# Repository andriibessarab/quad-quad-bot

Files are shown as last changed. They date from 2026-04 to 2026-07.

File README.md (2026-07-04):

<p>
  
</p>
<small>
  Custom desktop-size quadruped robot — from design and CAD to ROS 2 simulation and a physical build.
</small>

<hr/>

## About

**Quad-Quad Bot** is a quadruped (four-legged) robot built by me as a solo side-project. It spans the full mechatronics stack:

- **Mechanical** — from-scratch design, CAD in SolidWorks, and 3D-printed parts.
- **Electronics** — custom power distribution, motor drivers, onboard compute
- **Software** — ROS 2 (Jazzy), Gazebo Harmonic simulation, inverse kinematics, gait planning, and feedback loops.

<i> Current status: simulation is running with a trot gait. Hardware assembled. Currently tuning walking gaits(crawl, trot, and maybe gallop). </i>

<hr/>

## Gallery

<table>
  <tr>
    <td align="center" width="50%">
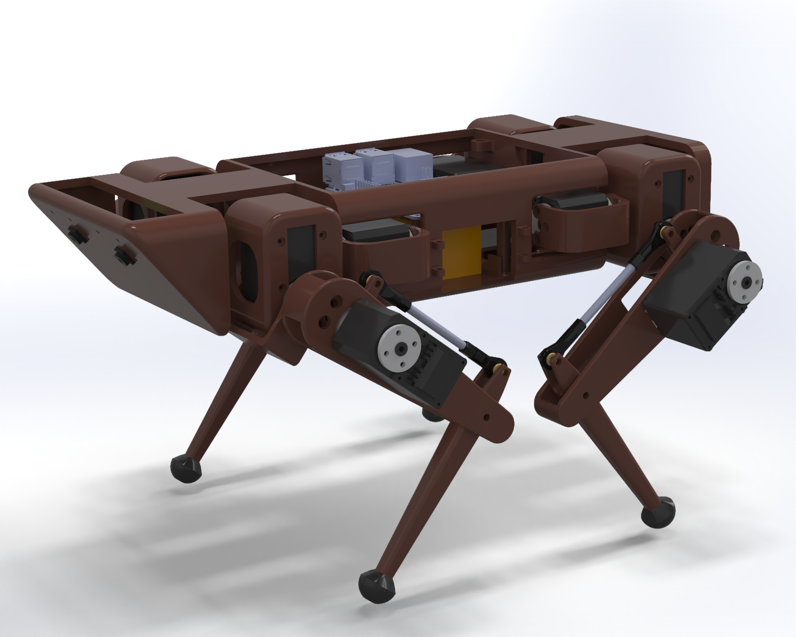
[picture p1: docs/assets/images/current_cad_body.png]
CAD render
      
      <br/><br/><b>CAD Model</b>
    </td>
    <td align="center" width="50%">
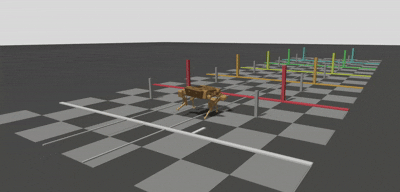
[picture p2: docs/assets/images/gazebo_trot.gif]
Gazebo simulation
      
      <br/><br/><b>Gazebo Trot</b>
    </td>
  </tr>
  <tr>
    <td align="center" width="50%">
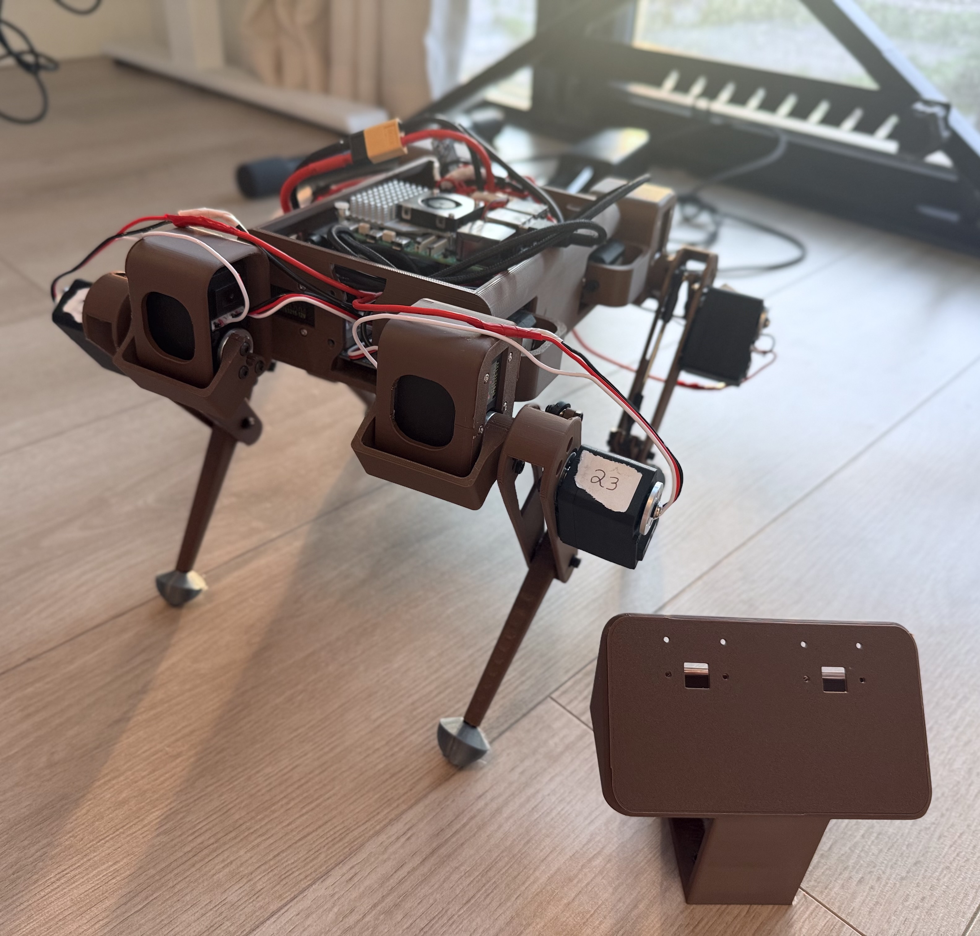
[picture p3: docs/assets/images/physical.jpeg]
Physical robot
      
      <br/><br/><b>Hardware <i>(WIP)</i></b>
    </td>
    <td align="center" width="50%">
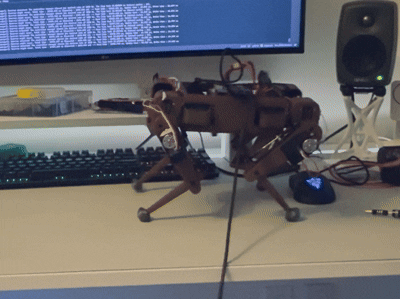
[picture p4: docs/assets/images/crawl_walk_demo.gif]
Walk Demo
      
      <br/><br/><b>Walk Demo</b>
    </td>
  </tr>
</table>

<hr/>

## Repository Structure

```
quad-quad-bot/
├── ros2_ws/         # ROS 2 workspace — all software (nodes, controllers, bringup)
├── design/
│   ├── cad/         # SolidWorks source files
│   ├── slicer/      # 3D print slicer projects
│   └── electrical/  # Wiring diagrams
└── docs/            # Technical documentation (MkDocs)
```

<hr/>

## Documentation
Full technical documentation can be found [here](https://quad-quad-bot.andriibessarab.com/). It is currently in TODO state.

<hr/>

<p><sub>Built by <a href="https://github.com/andriibessarab">Andrii Bessarab</a></sub></p>

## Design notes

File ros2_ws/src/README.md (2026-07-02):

# Packages

| Package | Description |
|---|---|
| `bot_bringup` | Top-level launch entry point for both sim and real hardware. |
| `bot_control` | Gait planner and locomotion commander nodes - computes foot targets and runs IK to produce joint commands. |
| `bot_description` | URDF/xacro robot model, joint limits, motor wiring config, and ros2_control hardware description. |
| `bot_hardware` | ros2_control `SystemInterface` plugin that drives all 12 STS servos over TTL-level, half-duplex, single-wire asynchronous serial  serial. |
| `bot_math` | Pure C++ library — IK solver and foot trajectory math. |
| `bot_sim` | Gazebo Harmonic world and robot spawn setup. |
| `bot_teleop` | Xbox controller → `/cmd_vel` via `joy_linux` and `teleop_twist_joy`. |

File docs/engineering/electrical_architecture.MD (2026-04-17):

# Electrical Architecture



---

## SS
The system has to primary tasks: to fly and to walk. Due to how different these two system operate - it was decided to take a "split-brain" approach.

Flying subsystem consistent 

Walking subsystem 

## Power Distribution

The system is powered by a single **850mAh 4S 95C LiPo battery**. Power is routed through an XT60 pigtail and split via a three-way junction to the SpeedyBee ESC, Matek Micro UBEC, and Hobbywing 25A UBEC. This parallel distribution isolates subsystems with fundamentally different voltage and current requirements.

### Logic Power
The **Matek Micro UBEC** steps down the primary battery voltage to a regulated 5V, supplying 1.5A continuous (2.5A peak). This provides the dedicated, low-current logic power required by the Raspberry Pi Zero processor.

### Leg Power
The **Hobbywing 25A UBEC** steps down battery voltage to 6.0V/7.4V to power the 12 Hiwonder servos. These servos possess a collective theoretical stall current of 30A (12 servos × 2.5A). A standard, lower-rated UBEC would fail under the load of demanding maneuvers.

Because standard 2.54mm pin headers are generally only rated for ~3A of continuous current, drawing 25A–50A through a single port would result in thermal failure. To safely manage this, the UBEC's 8 output ports are wired in parallel to form a custom high-current distribution bus. This architecture shares the load, reducing the maximum current draw per individual pin to safe operating margins (3.75A per pin under a 30A peak load) before distributing it out to the 12 servos.

The ground rail follows the same parallel bus architecture. In addition to the 12 servo ground returns, a dedicated synchronization wire connects this high-current ground bus directly to a GND pin on the PCA9685 to ensure a common zero-volt reference across the logic and actuation systems.

### Flight Power
The **SpeedyBee ESC** receives raw battery voltage to directly drive the four FlyFishRC Flash 1804 3500KV motors. The ESC also passes this raw battery voltage up to the SpeedyBee Flight Controller mounted on top of it, which regulates its own internal logic power via an integrated voltage regulator.

### Auxiliary Power Routing
* **PCA9685 (PWM Driver):** Receives 3.3V logic power from the Raspberry Pi. To prevent  thermal failure of the board's internal copper traces, the PCA9685's terminal block is deliberately bypassed. The 30A servo actuation current is routed entirely through the external parallel bus.
* **Radio Link:** The Radiomaster RP2 V2 TCXO receiver draws its 5V logic power directly from a dedicated 5V pad on the SpeedyBee FC.
* **Pi Cam:** Raspberry Pi Camera V2 is connected to Raspberry Pi through CSI cable which is used for both data and power transfer.

---

## Communications & Logic Architecture

Data routing across the system is strictly delineated by subsystem to ensure the Linux-based environment of the Raspberry Pi does not interrupt the real-time processing of the flight controller. The communication topologies are divided into the following discrete channels:

### Vision System (Raspberry Pi & Pi Camera)
* **Interface:** MIPI CSI-2
* **Implementation:** Connected via a dedicated flat ribbon cable.
* **Function:** Provides a high-bandwidth, direct memory access (DMA) pipeline for raw video data transfer from the camera module to the Pi Zero 2 W, enabling low-latency computer vision and automation processing.

### Kinematics Control Loop (Raspberry Pi & PCA9685)
* **Interface:** I2C Bus
* **Implementation:** Pi SDA connects to PCA9685 SDA; Pi SCL connects to PCA9685 SCL.
* **Function:** The Pi does complex calculations in ROS and transmits the resulting multi-channel positioning commands over the I2C bus to the PCA9685. The PCA9685 then generates the precise hardware-level PWM signals required to actuate the 12 Hiwonder servos.

### Companion Computer Link (Raspberry Pi & SpeedyBee FC)
* **Interface:** Bi-directional Asynchronous Serial (UART)
* **Implementation:** Crossed logic lines; Pi TX connects to FC RX, and Pi RX connects to FC TX.
* **Function:** The Raspberry Pi acts as a "Companion Computer" to the Flight Controller. This bi-directional link serves a dual purpose:
    1. **Telemetry Stream:** The Pi receives high-frequency IMU data from the FC.
    2. **Offboard Control:** Pi transmits high-level autonomous flight directives derived from its vision processing. The FC receives these commands and handles the critical, low-level PID motor mixing required to execute them safely.

### **Manual Pilot Override (SpeedyBee** FC & Radio Link)
* **Interface:** Serial (UART)
* **Implementation:** Radiomaster RP2 V2 TCXO receiver wired to the FC's TX and RX pads.
* **Function:** Provides a direct, hardware-level pilot override and fail-safe mechanism. Because it communicates directly with the Flight Controller, manual flight control and emergency motor-kill switches remain fully operational even in the event of a Raspberry Pi OS crash or automation loop failure.

---

## Pinout Tables
This will be added at later point.

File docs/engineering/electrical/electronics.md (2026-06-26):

# Electronics

## Compute Board

## Flight Stack

## Camera

## Radio Receiver

## Integration Notes

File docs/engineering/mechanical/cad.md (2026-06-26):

# CAD

## Design Overview

## SolidWorks Workflow

## Key Design Decisions

## Link Geometry & Dimensions

## Revision History

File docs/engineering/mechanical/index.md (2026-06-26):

# Mechanical

- [CAD](cad.md)
- [Manufacturing](manufacturing.md)

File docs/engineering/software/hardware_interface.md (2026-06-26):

# Hardware Interface

## STS3215 Servo Protocol

## ros2_control Plugin

## Servo ID Mapping

## Calibration Procedure

### Setting zero_count

### Setting direction

## Serial Port Setup

## Pre-Power Safety Checklist

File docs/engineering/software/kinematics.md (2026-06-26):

# Kinematics

## Limb Geometry

## HAA Derivation

## HFE / KFE Derivation

## Singularity Cases

## Link Dimensions

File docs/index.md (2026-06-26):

# Introduction

Current Cad

Hey there! I'm **Andrii** - a 1st-year **Tron student at Waterloo**. For a while, I have wanted to tackle a serious solo
robotics project, and this is the result.

In short, the goal is to build a **quadruped robot** (think Boston Dynamics) that can also transition into **flight mode
** (aka quadcopter). It is a unique challenge that will force me to get hands-on with a massive set of tools, including
**CAD, kinematics, ROS, simulations, 3D printing, electronics, vision processing**, and more.

What you are looking at is the technical documentation for this project, covering the full stack from CAD and electronics to kinematics and software.

I don’t have a set timeline or a final vision yet, so the scope is bound to change as I work through this project...

---

<div class="grid" markdown>

[Engineering Details](engineering/){: .md-button }

</div>

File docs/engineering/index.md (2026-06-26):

# Engineering

- [Mechanical](mechanical/index.md) — CAD, manufacturing, assembly
- [Electrical](electrical/index.md) — power distribution, wiring, electronics
- [Software](software/index.md) — ROS architecture, kinematics, gait, simulation
- [BOM](bom.md) — bill of materials

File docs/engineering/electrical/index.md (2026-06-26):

# Electrical

- [Power](power.md)
- [Wiring](wiring.md)
- [Electronics](electronics.md)

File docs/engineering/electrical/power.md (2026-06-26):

# Power

## Power Budget

## Battery

## Power Distribution

### Servo UBEC

### Compute UBEC

## Wiring Diagram

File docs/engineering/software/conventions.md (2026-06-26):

# Conventions

## Zero Position

## Joint Sign Conventions

### HAA (Hip Abduction/Adduction)

### HFE (Hip Flexion/Extension)

### KFE (Knee Flexion/Extension)

## IK Target Frame

## IK Output Conventions

## Commander Inversion Table

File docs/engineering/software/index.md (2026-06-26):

# Software

- [Conventions](conventions.md)
- [Kinematics](kinematics.md)
- [Gait](gait.md)
- [Architecture](architecture.md)
- [URDF / Xacro](urdf.md)
- [Simulation](simulation.md)
- [Hardware Interface](hardware_interface.md)

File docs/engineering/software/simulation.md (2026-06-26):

# Simulation

## Prerequisites

## Quick Start

## Manual Joint Testing

## Changing Meshes & Rebuilding URDF

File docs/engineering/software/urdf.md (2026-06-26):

# URDF / Xacro Structure

## File Hierarchy

## Joint Naming Convention

## Limb Macro Parameters

## Joint Limits

## Regenerating from SolidWorks Export

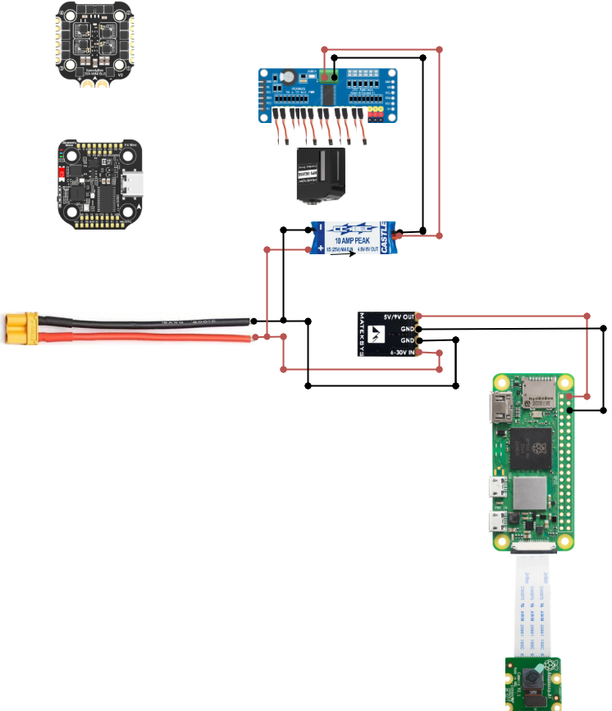
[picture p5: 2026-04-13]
electronics/schematics/main_electronics_scheme.drawio.png

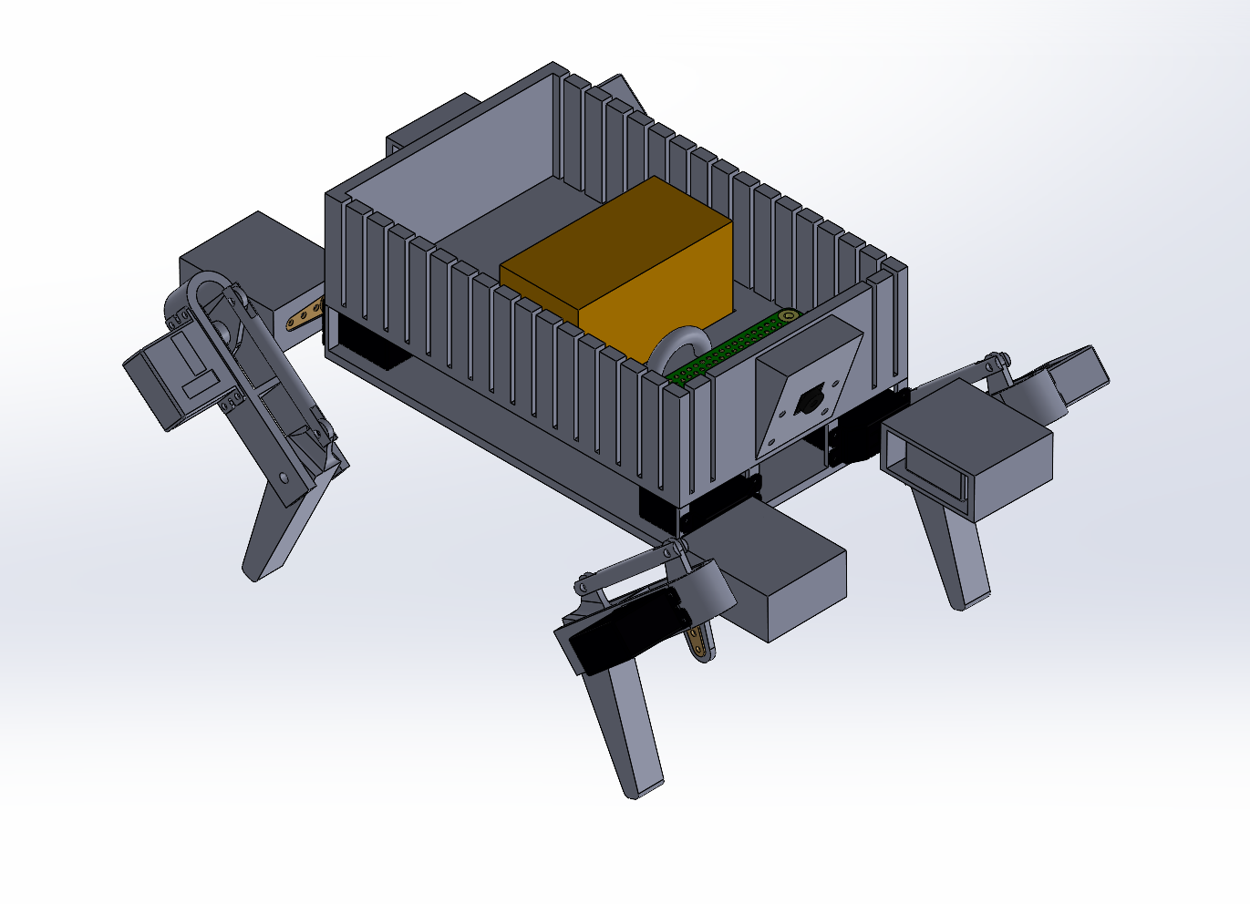
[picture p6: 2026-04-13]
docs/assets/images/cad_first_version.png

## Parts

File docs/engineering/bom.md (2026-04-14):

# Bill of Materials

## Compute & Vision

| Functional Name | Part Name | Qty | Mass (g) | Est. Cost (CAD) | Link |
|:---|:---|:----|:---|:---|:---|
| **High-Level Processor** | Raspberry Pi Zero 2 W  | 1 | 9.0 | 32.99 | [Amazon](https://www.amazon.ca/Raspberry-Zero-Wireless-Bluetooth-2021/dp/B09LH5SBPS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) |
| **Vision Sensor** | Raspberry Pi Camera V2 | 1 | 3.0 | 32.99 | [Amazon](https://www.amazon.ca/Raspberry-Pi-Camera-Module-Megapixel/dp/B01ER2SKFS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) |
| **SD Card** | SD Card | | | | |

## Flight Systems

| Component | Part Name | Qty | Mass (g) | Est. Cost (CAD) | Link |
|:---|:---|:----|:---|:---|:---|
| **Flight Stack** | SpeedyBee F405 Mini BLS 35A 20x20mm Stack | 1 | 13.5 | 89.99 | [Great Hobbies](https://www.greathobbies.com/productinfo/?prod_id=SPBF4MINI-ST) |
| **BLDC Flight Motors** | FlyFishRC Flash 1804 3500KV | 4 | 14.0 | 22.99 | [Rotor Village](https://rotorvillage.ca/flyfishrc-flash-1804-3500kv-freestyle-motor/) |
| **Propellers** | Gemfan Hurricane T3525 Props (2CW+2CCW) | 1 | 3.78 | 4.69 | [Rotor Village](https://rotorvillage.ca/gemfan-51433-hurricane-tri-blade-prop-2cw-2ccw/) |
| **Radio Link** | Radiomaster RP2 V2 TCXO ExpressLRS 2.4GHz Receiver | 1 | 0.55 | 27.99 | [Rotor Village](https://rotorvillage.ca/radiomaster-rp2-v2-tcxo-expresslrs-2-4ghz-receiver/) |

## Actuation & Limb Control

| Component | Part Name | Qty | Mass (g) | Est. Cost (CAD) | Link |
|:---|:---|:----|:---|:---|:---|
| **PWM PWM Servo Driver** | JZK PCA9685 16 Channel 12-Bit PWM Servo Motor Driver | 1 | 11.0 | 10.59 | [Amazon](https://www.amazon.ca/JZK-PCA9685-Channel-12-Bit-Arduino/dp/B06XSFFXQY) |
| **Limb Servos** | Hiwonder HPS-0618SG | 12  | 14.5 | 33.16 | [Amazon](https://www.amazon.com/Hiwonder-Coreless-0-06sec-Stainless-Robotic/dp/B09TVNFN5N) |
| **Joint Bearings** | F683ZZ Flanged Bearings | 12  | 1.8 | 16.59 / 10 | [Amazon](https://www.amazon.ca/uxcell-Flanged-Bearing-Shielded-Bearings/dp/B07Z3DRZX9) |

## Power Distribution

| Component | Part Name | Qty | Mass (g) | Est. Cost (CAD) | Link |
|:---|:---|:----|:---|:---|:---|
| **Battery** | Tattu R-Line 850mAh 4S 95C Lipo XT60 | 1 | 104 ± 20 | 30.99 | [Roter Village](https://rotorvillage.ca/tattu-r-line-850mah-4s-95c-lipo-xt60) |
| **High-Current Servo UBEC** | Hobbywing UBEC 25A HV | 1 | 74.0 | 106.99 | [RotorQuest](https://rotorquest.com/products/ubec-25a-hv) |
| **Processor UBEC** | Matek Micro BEC (5V/9V) | 1 | 1.0 | 13.99 / 3 | [Roter Village](https://rotorvillage.ca/Matek-Micro-BEC-6-30V-5V/9V-Adjustable/) |
| **Battery Pigtail** | Padarsey 2 Pair XT60 Connector 10CM Silicon Wire 14AWG | 1 | | 9.99 / 4 | [Amazon](https://www.amazon.ca/Padarsey-Connector-Female-Housing-Silicon/dp/B07BF8154S) |

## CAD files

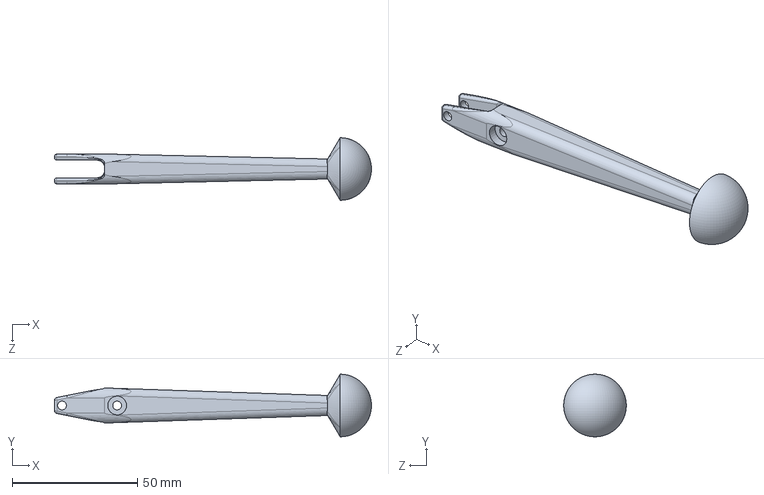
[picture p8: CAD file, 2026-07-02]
design/cad/parts/tibia.SLDPRT
126.5 x 25.0 x 25.0 mm

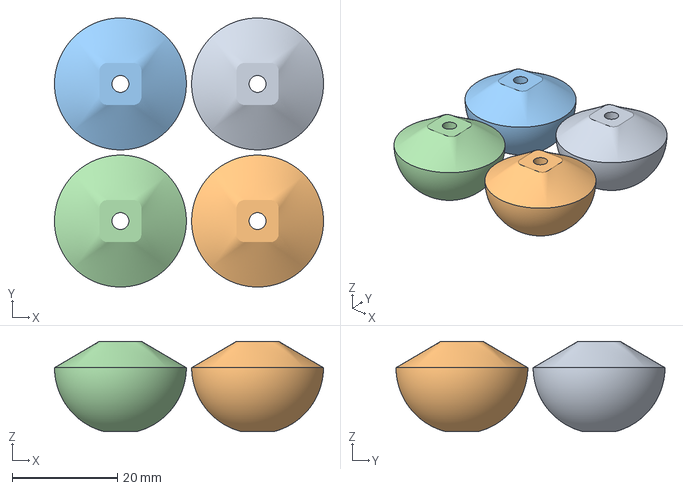
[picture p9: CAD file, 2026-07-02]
design/slicer/tibia_spherical_foot.3mf
51.0 x 51.0 x 17.1 mm
tibia_spherical_foot.STEP x 4

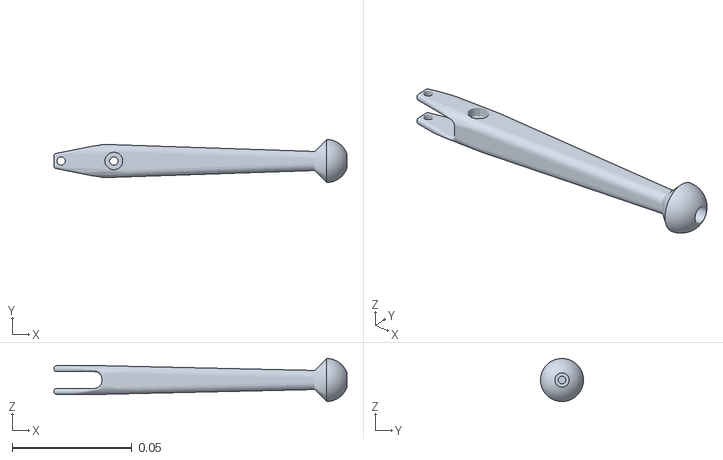
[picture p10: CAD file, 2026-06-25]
ros2_ws/src/bot_description/meshes/tibia_link.STL
0.122 x 0.018 x 0.018

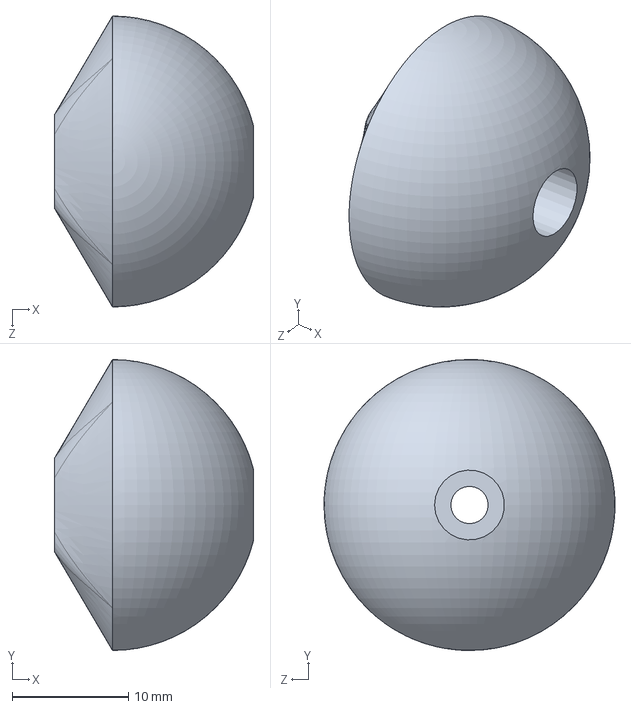
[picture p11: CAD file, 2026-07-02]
design/cad/parts/tibia_spherical_foot.SLDPRT
17.1 x 25.0 x 25.0 mm

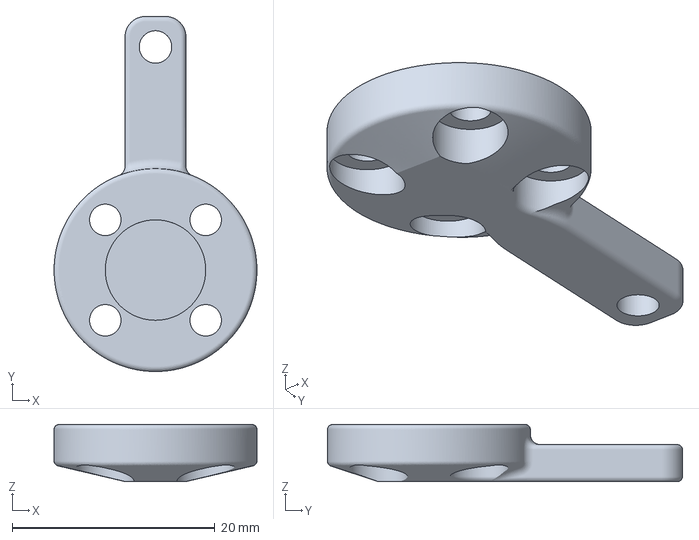
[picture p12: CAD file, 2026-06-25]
design/slicer/link_tab.3mf
20.0 x 35.0 x 5.64 mm

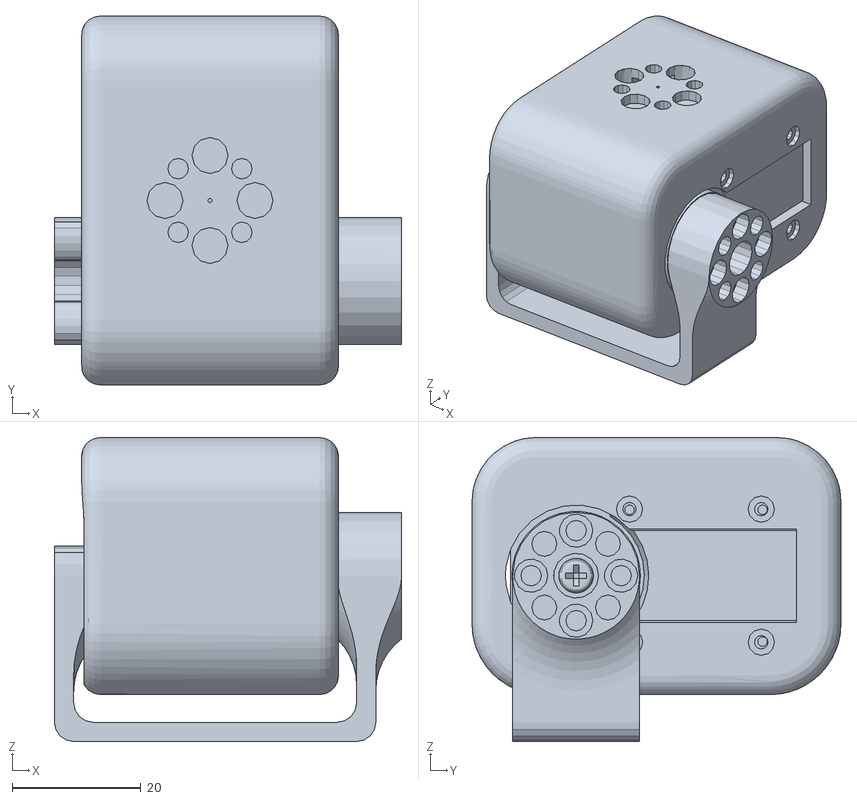
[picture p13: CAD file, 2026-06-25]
ros2_ws/src/bot_description/meshes/inverted_shoulder_link.STL
54.0 x 57.4 x 47.3

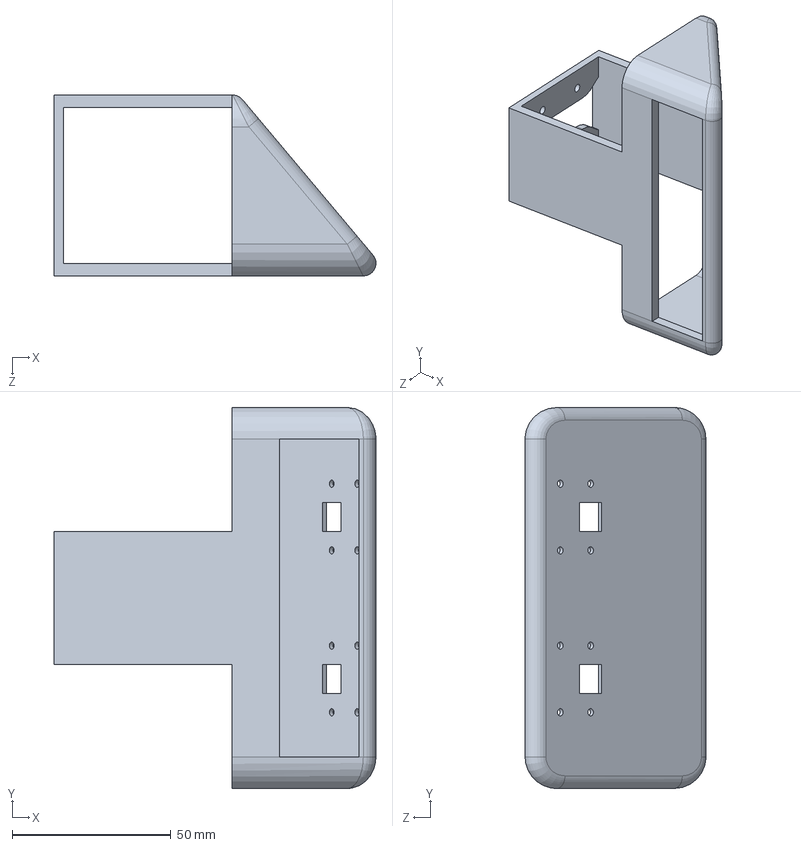
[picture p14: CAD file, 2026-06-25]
design/cad/parts/casing_front.SLDPRT
101.4 x 120.0 x 57.0 mm

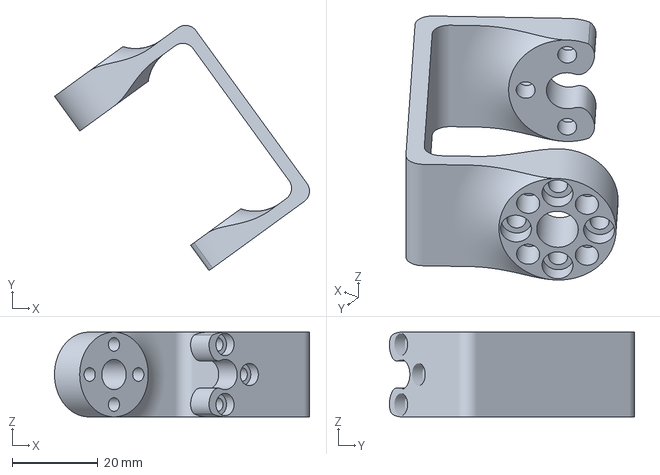
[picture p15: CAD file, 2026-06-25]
design/slicer/sts3215_coaxial_stradded_bracket_hfe.3mf
59.4 x 57.1 x 19.7 mm

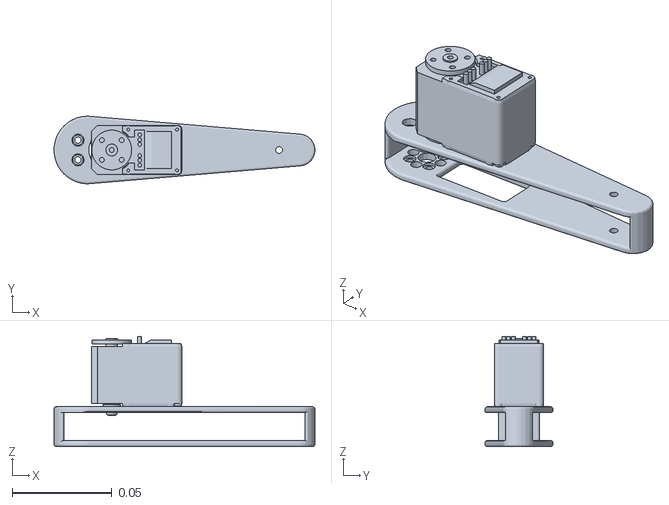
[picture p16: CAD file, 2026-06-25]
ros2_ws/src/bot_description/meshes/femur_link.STL
0.131 x 0.034 x 0.0553

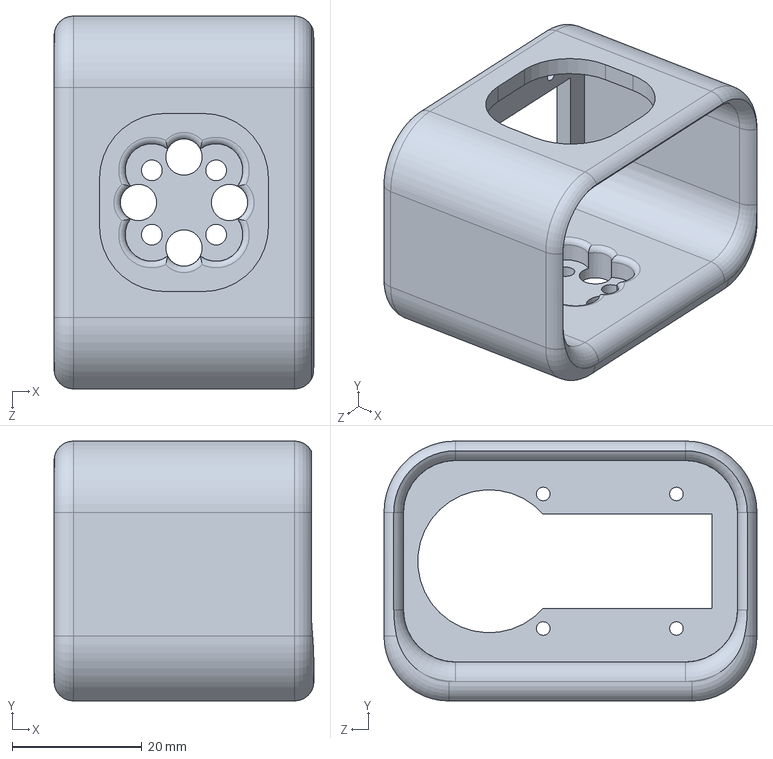
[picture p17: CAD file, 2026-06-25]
design/cad/parts/mirrored_shoulder.SLDPRT
40.0 x 40.0 x 57.4 mm

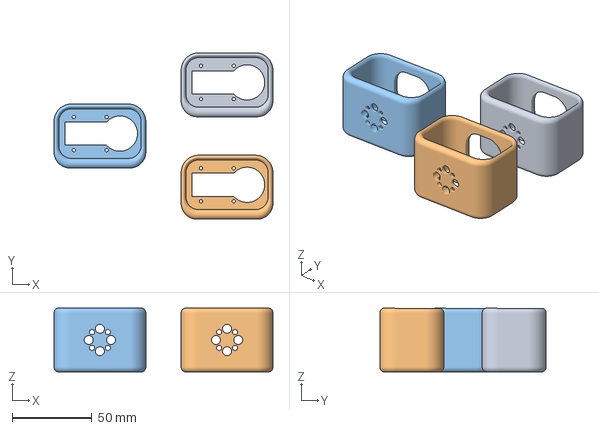
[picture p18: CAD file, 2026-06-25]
design/slicer/shoulder.3mf
136.9 x 104.0 x 40.0 mm
shoulder.STEP x 3

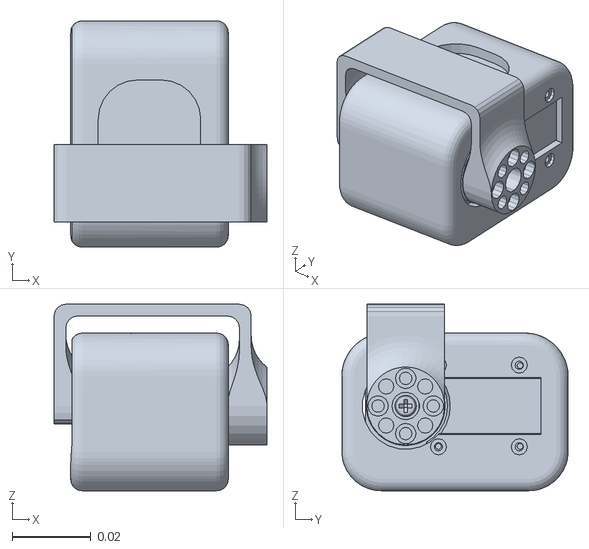
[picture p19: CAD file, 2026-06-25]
ros2_ws/src/bot_description/meshes/shoulder_link.STL
0.054 x 0.0574 x 0.0473

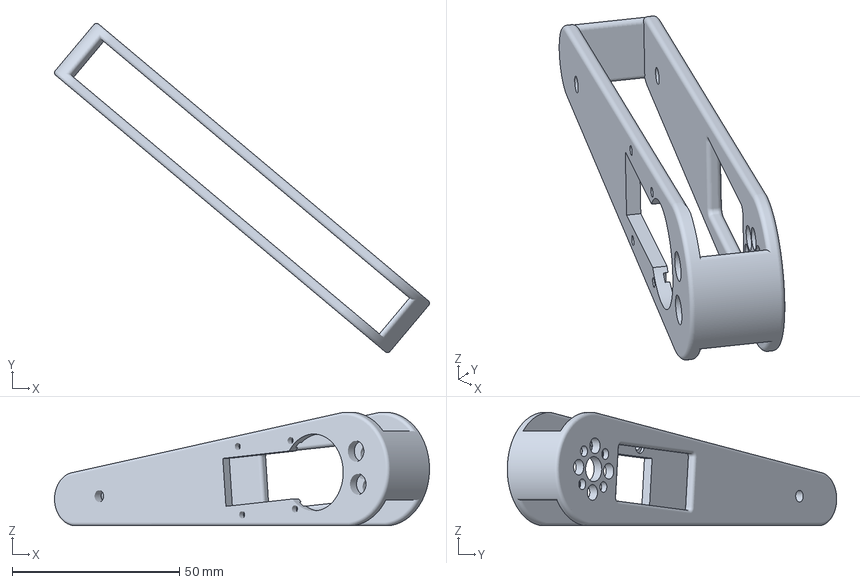
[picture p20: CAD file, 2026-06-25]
design/slicer/femur.3mf
112.2 x 98.5 x 33.9 mm

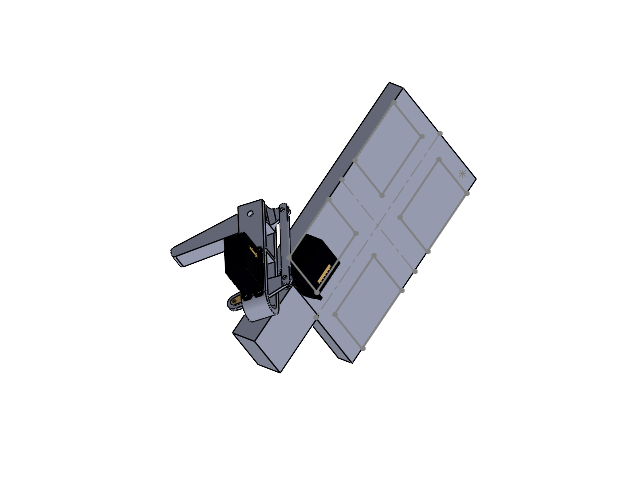
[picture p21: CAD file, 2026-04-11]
cad/Body.SLDASM
parttruc x 3
Tibia
Femur
Knee Link Rod
Knee Link Tab
servoPWM x 3
Shoulder
Part1^Body

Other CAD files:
design/cad/assemblies/limb_sub.SLDASM
design/cad/assemblies/chassis_sub.SLDASM
design/cad/assemblies/bot_master_assembly.SLDASM
design/cad/parts/shoulder.SLDPRT
design/cad/cots/actuators/HiWonder_HPS-0618SG/banhlai.SLDPRT
design/cad/cots/actuators/HiWonder_HPS-0618SG/parttruc.SLDPRT
design/cad/cots/actuators/HiWonder_HPS-0618SG/servoPWM.SLDPRT
design/cad/cots/actuators/STS3215_03a v1.step
design/cad/cots/electronics/KCD4_ROCKET_SWITCH.SLDPRT
design/cad/cots/electronics/PCA9685.step
design/cad/cots/electronics/RaspberryPi5.step
design/cad/cots/electronics/raspberry-pi-camera-v2.SLDPRT
design/cad/cots/electronics/‎WSH-SBS-01.SLDPRT
design/cad/cots/fasteners/Metric_Socket_Cap_Head_Screws/M3/Screw_DIN_912_M3x10F_A2.SLDPRT
design/cad/cots/fasteners/Metric_Socket_Cap_Head_Screws/M3/Screw_DIN_912_M3x12F_A2.SLDPRT
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

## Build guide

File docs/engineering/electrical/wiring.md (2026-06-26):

# Wiring

## Servo Bus

## Connector Types

## Harness Layout

## Pinouts

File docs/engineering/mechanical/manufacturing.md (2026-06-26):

# Manufacturing

## 3D Printing

### Print Settings

### Material

### Tolerances & Fit

## Assembly Order

## Known Issues & Mitigations

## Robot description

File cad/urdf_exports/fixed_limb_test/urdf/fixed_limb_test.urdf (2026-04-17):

<?xml version="1.0" encoding="utf-8"?>
<!-- This URDF was automatically created by SolidWorks to URDF Exporter! Originally created by Stephen Brawner (brawner@gmail.com) 
     Commit Version: 1.6.0-4-g7f85cfe  Build Version: 1.6.7995.38578
     For more information, please see http://wiki.ros.org/sw_urdf_exporter -->
<robot name="fixed_limb_test">
  <link name="base_link">
    <inertial>
      <origin xyz="0.012807313311312 0.00598090852226242 -0.0117251285139543" rpy="0 0 0" />
      <mass value="0.00723402556361831" />
      <inertia ixx="4.05147247523767E-07" ixy="3.01231584549377E-10" ixz="-1.88167986432032E-08" iyy="7.38938259329422E-07" iyz="7.90595902470049E-10" izz="5.0342421323583E-07" />
    </inertial>
    <visual>
      <origin xyz="0 0 0" rpy="0 0 0" />
      <geometry>
        <mesh filename="package://fixed_limb_test/meshes/base_link.STL" />
      </geometry>
      <material name="">
        <color rgba="0.00392156862745098 0 0.0196078431372549 1" />
      </material>
    </visual>
    <collision>
      <origin xyz="0 0 0" rpy="0 0 0" />
      <geometry>
        <mesh filename="package://fixed_limb_test/meshes/base_link.STL" />
      </geometry>
    </collision>
  </link>
  <link name="shoulder_link">
    <inertial>
      <origin xyz="0.00770399429191724 9.32504877206378E-06 0.0207339193469641" rpy="0 0 0" />
      <mass value="0.0148104574438063" />
      <inertia ixx="1.88189230614178E-06" ixy="3.01231584549858E-10" ixz="1.68325026936694E-08" iyy="2.59134654836223E-06" iyz="-7.90595902469875E-10" izz="1.39963201919848E-06" />
    </inertial>
    <visual>
      <origin xyz="0 0 0" rpy="0 0 0" />
      <geometry>
        <mesh filename="package://fixed_limb_test/meshes/shoulder_link.STL" />
      </geometry>
      <material name="">
        <color rgba="0.545098039215686 0.615686274509804 0.858823529411765 1" />
      </material>
    </visual>
    <collision>
      <origin xyz="0 0 0" rpy="0 0 0" />
      <geometry>
        <mesh filename="package://fixed_limb_test/meshes/shoulder_link.STL" />
      </geometry>
    </collision>
  </link>
  <joint name="haa_joint" type="revolute">
    <origin xyz="-0.001 0.006 -0.016" rpy="3.1416 -1.5708 0" />
    <parent link="base_link" />
    <child link="shoulder_link" />
    <axis xyz="0 0 1" />
    <limit lower="-1.5708" upper="0" effort="0" velocity="0" />
  </joint>
  <link name="femur_link">
    <inertial>
      <origin xyz="0.0124792168310497 9.99428181540189E-06 0.0185705130302731" rpy="0 0 0" />
      <mass value="0.0138239022547814" />
      <inertia ixx="8.42245738682422E-07" ixy="-7.91960713042997E-10" ixz="-9.47919040177247E-08" iyy="3.58798405876978E-06" iyz="-3.01970991415103E-10" izz="3.1267090240501E-06" />
    </inertial>
    <visual>
      <origin xyz="0 0 0" rpy="0 0 0" />
      <geometry>
        <mesh filename="package://fixed_limb_test/meshes/femur_link.STL" />
      </geometry>
      <material name="">
        <color rgba="0.866666666666667 0.909803921568627 1 1" />
      </material>
    </visual>
    <collision>
      <origin xyz="0 0 0" rpy="0 0 0" />
      <geometry>
        <mesh filename="package://fixed_limb_test/meshes/femur_link.STL" />
      </geometry>
    </collision>
  </link>
  <joint name="hfe_joint" type="revolute">
    <origin xyz="0.020875 0 0.0165" rpy="0 1.5708 0" />
    <parent link="shoulder_link" />
    <child link="femur_link" />
    <axis xyz="0 0 -1" />
    <limit lower="0" upper="3.14" effort="0" velocity="0" />
  </joint>
  <link name="tibia_link">
    <inertial>
      <origin xyz="0.0156981068181742 3.55361015266786E-09 7.93462496675047E-05" rpy="0 0 0" />
      <mass value="0.0070755567397191" />
      <inertia ixx="1.28214686803871E-07" ixy="4.5956055502833E-13" ixz="1.45828471109314E-08" iyy="1.81740201742321E-06" iyz="-7.36270952752015E-14" izz="1.83619400245263E-06" />
    </inertial>
    <visual>
      <origin xyz="0 0 0" rpy="0 0 0" />
      <geometry>
        <mesh filename="package://fixed_limb_test/meshes/tibia_link.STL" />
      </geometry>
      <material name="">
        <color rgba="0.545098039215686 0.615686274509804 0.858823529411765 1" />
      </material>
    </visual>
    <collision>
      <origin xyz="0 0 0" rpy="0 0 0" />
      <geometry>
        <mesh filename="package://fixed_limb_test/meshes/tibia_link.STL" />
      </geometry>
    </collision>
  </link>
  <joint name="knee_joint" type="revolute">
    <origin xyz="0.046 0 0.0106" rpy="-3.1416 0 1.5708" />
    <parent link="femur_link" />
    <child link="tibia_link" />
    <axis xyz="0 0 1" />
    <limit lower="-0.87267" upper="0.87267" effort="0" velocity="0" />
  </joint>
  <link name="tab_link">
    <inertial>
      <origin xyz="-0.00203367196621368 -6.01949046163952E-16 0.00395500792852426" rpy="0 0 0" />
      <mass value="0.00116134718742782" />
      <inertia ixx="9.1005400789047E-09" ixy="-7.94186594852218E-22" ixz="1.61623668129035E-09" iyy="8.60231140276365E-08" iyz="-2.37565391241938E-23" izz="9.3647667205365E-08" />
    </inertial>
    <visual>
      <origin xyz="0 0 0" rpy="0 0 0" />
      <geometry>
        <mesh filename="package://fixed_limb_test/meshes/tab_link.STL" />
      </geometry>
      <material name="">
        <color rgba="0.866666666666667 0.909803921568627 1 1" />
      </material>
    </visual>
    <collision>
      <origin xyz="0 0 0" rpy="0 0 0" />
      <geometry>
        <mesh filename="package://fixed_limb_test/meshes/tab_link.STL" />
      </geometry>
    </collision>
  </link>
  <joint name="kfe_motor_joint" type="revolute">
    <origin xyz="0.002 0 0.0132" rpy="-3.1416 0 -1.5708" />
    <parent link="femur_link" />
    <child link="tab_link" />
    <axis xyz="0 0 -1" />
    <limit lower="-0.87267" upper="0.87267" effort="0" velocity="0" />
  </joint>
  <link name="rod_link">
    <inertial>
      <origin xyz="0.021999975174988 7.77439050636541E-09 -6.17363184046704E-08" rpy="0 0 0" />
      <mass value="0.000929490166689096" />
      <inertia ixx="3.11724892800746E-09" ixy="-1.76984253516657E-14" ixz="1.0644090388813E-13" iyy="1.38486128282688E-07" iyz="5.69419412480685E-14" izz="1.38113398710736E-07" />
    </inertial>
    <visual>
      <origin xyz="0 0 0" rpy="0 0 0" />
      <geometry>
        <mesh filename="package://fixed_limb_test/meshes/rod_link.STL" />
      </geometry>
      <material name="">
        <color rgba="0.545098039215686 0.615686274509804 0.858823529411765 1" />
      </material>
    </visual>
    <collision>
      <origin xyz="0 0 0" rpy="0 0 0" />
      <geometry>
        <mesh filename="package://fixed_limb_test/meshes/rod_link.STL" />
      </geometry>
    </collision>
  </link>
  <joint name="rod_joint" type="revolute">
    <origin xyz="0.015 0 0.0045" rpy="0 0 -1.5708" />
    <parent link="tab_link" />
    <child link="rod_link" />
    <axis xyz="0 0 -1" />
    <limit lower="-0.87267" upper="0.87267" effort="0" velocity="0" />
  </joint>
</robot>

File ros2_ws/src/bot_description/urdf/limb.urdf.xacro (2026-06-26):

<?xml version="1.0" encoding="utf-8"?>

<robot xmlns:xacro="http://www.ros.org/wiki/xacro" name="limb">
    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
    <xacro:property name="limits" value="${xacro.load_yaml('$(find bot_description)/config/joint_limits.yaml')}"/>

    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
    <xacro:macro name="_limb_core" params="prefix inverted_shoulder hfe_axis_mult kfe_axis_mult">
        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
        <link name="${prefix}shoulder_link">
            <inertial>
                <origin xyz="0.00189283967211911 -0.00149022104022392 0.0209651260942884" rpy="0 0 0" />
                <mass value="0.0772984767866564" />
                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
            </inertial>
            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
        </link>
        <link name="${prefix}femur_link">
            <inertial>
                <origin xyz="0.0323249229136636 -9.62316571824495E-07 0.0265797029719004" rpy="0 0 0" />
                <mass value="0.0561441430721167" />
                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
            </inertial>
            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
        </link>
        <link name="${prefix}tibia_link">
            <inertial>
                <origin xyz="0.039043936151174 -1.78287788882986E-07 -1.41708728744472E-07" rpy="0 0 0" />
                <mass value="0.0146532231932923" />
                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
            </inertial>
            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
        </link>

        <joint name="${prefix}hfe_joint" type="revolute">
            <xacro:if value="${inverted_shoulder}">
                <origin xyz="0.0298000000000001 -0.0124999999999999 -0.0214999999999999" rpy="-1.5707963267949 0 -1.5707963267949"/>
            </xacro:if>
            <xacro:unless value="${inverted_shoulder}">
                <origin xyz="0.0298000000000001 -0.0124999999999999 0.0214999999999999" rpy="-1.5707963267949 0 -1.5707963267949"/>
            </xacro:unless>

            <parent link="${prefix}shoulder_link"/>
            <child link="${prefix}femur_link"/>
            <axis xyz="0 0 ${hfe_axis_mult * -1}"/>
            <limit lower="${limits['hfe']['lower']}" upper="${limits['hfe']['upper']}" effort="${limits['hfe']['effort']}" velocity="${limits['hfe']['velocity']}"/>
        </joint>

        <joint name="${prefix}kfe_joint" type="revolute">
            <origin xyz="0.0960572429044665 0 0.00999999999999993" rpy="-3.14159265358979 0 0"/>
            <parent link="${prefix}femur_link"/>
            <child link="${prefix}tibia_link"/>
            <axis xyz="0 0 ${kfe_axis_mult * 1}"/>
            <limit lower="${limits['kfe']['lower']}" upper="${limits['kfe']['upper']}" effort="${limits['kfe']['effort']}" velocity="${limits['kfe']['velocity']}"/>
        </joint>
    </xacro:macro>

    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
    <xacro:macro name="limb" params="prefix x y z r p yw parent_link:=body_link inverted_shoulder hfe_axis_mult kfe_axis_mult">
        <xacro:_limb_core prefix="${prefix}_" inverted_shoulder="${inverted_shoulder}" hfe_axis_mult="${hfe_axis_mult}" kfe_axis_mult="${kfe_axis_mult}"/>
        <joint name="${prefix}_haa_joint" type="revolute">
            <parent link="${parent_link}"/>
            <child link="${prefix}_shoulder_link"/>
            <origin xyz="${x} ${y} ${z}" rpy="${r} ${p} ${yw}"/>
            <axis xyz="0 0 1"/>
            <limit lower="${limits['haa']['lower']}" upper="${limits['haa']['upper']}" effort="${limits['haa']['effort']}" velocity="${limits['haa']['velocity']}"/>
        </joint>
    </xacro:macro>
</robot>

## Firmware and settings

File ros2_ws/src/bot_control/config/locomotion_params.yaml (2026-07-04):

/**:
  ros__parameters:
    # These entries define the per-limb joint suffixes and limb prefixes.
    # When concatenated as "<prefix>_<joint>", the resulting joint list must
    # match the exact order used in controllers.yaml.
    joints:
      - haa_joint
      - hfe_joint
      - kfe_joint
    limb_prefixes:
      - fr
      - fl
      - br
      - bl

    # Lengths of shoulder (l1), femur (l2) and tibia (l3) links
    l1_len: 0.02980  # hip offset   (m)
    l2_len: 0.09606  # femur length (m)
    l3_len: 0.09750  # tibia Length (m)

    # Home position
    home_x: 0.0
    home_y: 0.0298
    home_z: -0.16

    # Sourced from leg_x/leg_y in robot.urdf.xacro.
    hip_x_offset: 0.0828  # fwd/bwd distance from body center to hip    (m)
    hip_y_offset: 0.0560  # left/right distance from body center to hip (m)

    limb_info: # needed to account for inversions
      fr:
        is_right: true
        is_back: false
      fl:
        is_right: false
        is_back: false
      br:
        is_right: true
        is_back: true
      bl:
        is_right: false
        is_back: true

locomotion_commander:
  ros__parameters:
    command_dispatch_frequency: 100.0  # Hz

gait_planner:
  ros__parameters:
    control_loop_frequency: 100.0  # Hz

    # Gait timing, shared by trot and crawl modes.
    # duty factor = stance / (stance + swing)
    # ideally 0.5 for trot; 0.75 for crawl
    step_height: 0.037    # foot lift height during swing  (m)
    swing_duration: 0.3   # time for swing phase            (s)
    stance_duration: 0.9  # time for stance phase           (s)

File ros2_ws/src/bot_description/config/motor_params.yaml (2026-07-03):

# Hardware configuration for the physical robot.

bus:
  serial_port: /dev/ttyACM0
  baud_rate: 1000000           # 1Mbps. Serial communication speed between your computer and the servo bu
  max_velocity_rad_per_s: 4.2  # Software velocity clamp: max rad/s any joint can move per write() cycle.
  servo_speed_units: 2900       # Additional ardware-enforced speed cap on top of the software clamp above.
  servo_acc_units: 200           # Hardware acceleration ramp.

# Per-joint motor wiring.
#
# motor_id:     ID burned onto the servo
# direction:    +1 or -1. Flips motor direction
# offset_ticks: 0-4095. Value where the joint is at URDF zero (0 rad).
#     - haa: halfway between lower and upper bounds
#     - hfe: perpendicular to the ground
#     - kfe: perpendicular to ground (since physically cannot go - find value at right angle
#            with femur and offset by +1024 for +1 direction, -1024 for -1 direction)
# lower_ticks:  Minimum tick the joint can physically reach.
# upper_ticks:  Maximum tick the joint can physically reach.

joints:
  fr_haa_joint: { motor_id: 11, direction: +1, offset_ticks: 2056, lower_ticks: 1614, upper_ticks: 2499 }
  fr_hfe_joint: { motor_id: 12, direction: -1, offset_ticks: 1456, lower_ticks: 1223, upper_ticks: 3292 }
  fr_kfe_joint: { motor_id: 13, direction: +1, offset_ticks: 2177, lower_ticks: 2964, upper_ticks: 3697 }  # measured offset: 3201

  fl_haa_joint: { motor_id: 21, direction: -1, offset_ticks: 1897, lower_ticks: 1461, upper_ticks: 2333 }
  fl_hfe_joint: { motor_id: 22, direction: +1, offset_ticks: 2087, lower_ticks: 215,  upper_ticks: 2295 }
  fl_kfe_joint: { motor_id: 23, direction: -1, offset_ticks: 2189, lower_ticks: 753,  upper_ticks: 1396 }  # measured offset: 1165

  br_haa_joint: { motor_id: 31, direction: -1, offset_ticks: 2389, lower_ticks: 1908, upper_ticks: 2870 }
  br_hfe_joint: { motor_id: 32, direction: +1, offset_ticks: 2785, lower_ticks: 922,  upper_ticks: 3005 }
  br_kfe_joint: { motor_id: 33, direction: -1, offset_ticks: 2822, lower_ticks: 1331, upper_ticks: 2045 }  # measured offset: 1798

  bl_haa_joint: { motor_id: 41, direction: +1, offset_ticks: 1399, lower_ticks: 939,  upper_ticks: 1858 }
  bl_hfe_joint: { motor_id: 42, direction: -1, offset_ticks: 1535, lower_ticks: 1319, upper_ticks: 3385 }
  bl_kfe_joint: { motor_id: 43, direction: +1, offset_ticks: 2041, lower_ticks: 2863, upper_ticks: 3459 }  # measured offset: 3065

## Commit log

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2026-04-11 feat(cad): add initial geometry for knee link rod and tab
    [Knee Link Rod.SLDPRT, Knee Link Tab.SLDPRT]
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2026-04-11 feat(cad): mate enclosed shoulder casing to the motor
    [Limb.SLDASM]
2026-04-11 fix(cad): decrease tibia link tab thickness
    [Limb.SLDASM, Tibia.SLDPRT]
2026-04-11 fix(cad): fix clearance issues in limb and implement improvements following issues in rough print
    [Femur.SLDPRT, Knee Link Rod.SLDPRT, Knee Link Tab.SLDPRT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]
2026-04-11 feat(cad): create body assembly with a single limb
    [Body.SLDASM]
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2026-04-12 feat(cad): add initial layout of top deck with pi and battery mounts
    [Top Deck.SLDPRT]
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2026-04-12 feat(cad): add mount for pi camera on top deck + lower pi standoffs
    [Top Deck.SLDPRT]
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2026-04-12 chore(cad): factor out bottom deck into external part
    [Bottom Deck.SLDPRT]
2026-04-12 fix(cad): rotate shoulder slot to prevent limb from hitting body
    [Limb.SLDASM, Shoulder.SLDPRT]
2026-04-12 feat(cad): add front-right limb and motors for front-left and back-right limbs
    [Bottom Deck.SLDPRT, Limb.SLDASM]
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2026-04-12 feat(cad): use mirror tool to add all four limbs based on one cad
    [Mirror Limb Back-Left.SLDASM, Mirror Limb Back-Right.SLDASM, Mirror Limb Front-Left.SLDASM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]
2026-04-12 fix(cad): remount shoulder motors to be on the outside of the body
2026-04-12 feat(cad): redesign pi cam mount to be at 20 degrees
    [Top Deck.SLDPRT]
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2026-04-13 fix(ci): switch deploy-docs to use GitHub Pages actions workflow
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2026-04-14 docs(bom): swap out Castle UBEC for Hobbywing 25A HV to ensure sufficient ampirage + switch to thicker XT60 battery connection
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2026-04-14 feat(cad): filet limb parts - automatic mirros parts
    [Limb.SLDASM, Mirror Limb Back-Left.SLDASM, Mirror Limb Back-Right.SLDASM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]
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2026-04-17 feat(cad): add material and mass to limb parts
    [Femur.SLDPRT, Knee Link Rod.SLDPRT, Knee Link Tab.SLDPRT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]
2026-04-17 feat(cad): create single limb assembly and set up urdf property manager
    [Fixed Limb Test.SLDASM, Limb.SLDASM, servoPWM.SLDPRT]
2026-04-17 chore(cad): remove spaces from cad names for stable linux performance with URDF
    [Bottom Deck.SLDPRT, Fixed Limb Test.SLDASM, Knee Link Rod.SLDPRT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]
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2026-04-22 feat(ros2): set up ros2 description and sim packages
    [base_link.STL, femur_link.STL, fixed_limb_test.csv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]
2026-04-28 bug(urdf): rotate haa joint by pi rads
    [quad_quad_limb.urdf]
2026-04-28 chore(urdf): reformat limb urdf to cleanly seperate joitns and links
    [quad_quad_limb.urdf]
2026-04-28 urdf: rescale inertias and add effort values to joints
    [quad_quad_limb.urdf]
2026-04-28 feat(ros2 bot_control): configure ros2_control and joint trajectory controller for limb
    [controllers.yaml]
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2026-04-28 feat(config): set limb controller to 1000Hz to match Gazebo
    [controllers.yaml]
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2026-04-30 feat(ros/bot_control): create send_goal method that waits for action server to start and assigns joints in goal.trajectory
    [controllers.yaml]
2026-04-30 chore(ros): split control and command code into seperate packages
    [controllers.yaml]
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2026-05-01 fix(ros/urdf): adjust haa and hfe bounds to prevent limit sticking
    [quad_quad_limb.urdf.xacro]
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2026-05-04 chore(ros/bot_description): match urdf joint interface tags to documented standards
    [quad_quad_limb.urdf.xacro]
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2026-05-06 feat(ros/bot_command): swap to position_controllers/JointGroupPositionController
    [controllers.yaml]
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2026-05-06 refactor(cad): delete fixed limb assembly
    [fixed_limb_test.SLDASM]
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2026-05-06 feat(cad): tune urdf settings for export in assemblies
    [limb.SLDASM]
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2026-05-07 fix(urdf): reexport meshes in correctr units (meters)
    [femur.STL, haa_horn.STL, hfe_horn.STL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]
2026-05-07 feat(urdf): create base_link to correctly orient body_link
    [body.urdf.xacro]
2026-05-07 feat(urdf): define limb xacro macro and prefix the shoulder link
    [limb.urdf.xacro]
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2026-05-07 feat(urdf): correctly position hfe and kfe joints
    [limb.urdf.xacro]
2026-05-07 fix(ros/bot_description): add joint state publisher to preview launch script
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2026-05-07 feat(ros/bot_description): correctly connect the inverted limbs (fl and br)
    [limb.urdf.xacro, robot.urdf.xacro]
2026-05-07 chore(ros/bot_description): bring joint limits into external yaml file
    [joint_limits.yaml]
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2026-05-07 refactor(ros/robot_description): encapsulate limb assembly in limb macro and remove robot add_limb
    [limb.urdf.xacro, robot.urdf.xacro]
2026-05-07 Feat(ros/bot_description): add ros2_control xacro macro for the 12 joints
    [ros2_control.urdf.xacro]
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2026-05-07 chore(ros/bot_description): make robot xacro sim-aware and wire ros2_control and gazebo overlays
    [robot.urdf.xacro]
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2026-05-07 fix(ros2): update joint names to include all limbs in bot_control and bot_command
    [controllers.yaml]
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2026-05-08 refactor(urdf): redefine limb joint origins so zero angles match I-pose
    [limb.urdf.xacro]
2026-05-08 refactor(urdf): normalize limb joint axis directions across all legs
    [limb.urdf.xacro]
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2026-05-09 refactor(ros/bot_control): merge bot_command, bot_gait, and bot_control into a single pkg
    [controllers.yaml]
2026-05-12 feat(cad): redesign body WIP
    [casing.SLDPRT, servoPWM.SLDPRT]
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2026-05-12 feat(cad): design circular shoulder such that kfe and hfe motors are coradial
    [MirrorMirrorparttruc.SLDPRT, MirrorMirrorservoPWM.SLDPRT, Mirrorparttruc.SLDPRT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]
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2026-05-12 feat(cad): limb redesign WIP - add two-part shoulder and new femur and tibia
    [casing.SLDPRT, femur.SLDPRT, limb.SLDASM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]
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2026-05-13 feat(cad): substite link and knee's cantilever joints with bearing-supported joints
    [femur.SLDPRT, link_tab.SLDPRT, tibia.SLDPRT]
2026-05-14 feat(cad): add new cots parts and reorganize cots directory
    [3684N11_Corrosion-Resistant Aluminum Gt Timing Belt Pulley.SLDPRT, 54548-2271, 22 Pin FPC Connector, Raspberry Pi Zero 2 W.SLDPRT, 57155K541_Ball Bearing (1).S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]
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2026-05-14 feat(cad): make tibia and femur exactly 80mm kinematic length
    [femur.SLDPRT, tibia.SLDPRT]
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2026-05-20 feat(cad): make femur longer and mount KFE at femur for simplicity
    [femur.SLDPRT]
2026-05-20 feat(cad): design new smaller shoulder for new actuator
    [shoulder.SLDPRT]
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2026-05-20 feat(cad): change casing dimensions and create mounts for new servos and PBD
    [casing.SLDPRT]
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2026-05-20 feat(cad): mate redesigned changes in assemblies
    [bot_master_assembly.SLDASM, chassis_sub.SLDASM, limb_sub.SLDASM]
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2026-05-20 feat(urdf): replace meshes with new ones
    [body.STL, chassis_link.STL, femur.STL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]
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2026-05-20 fix(cad): remove gaps in wall mounting back haa servos
    [bot_master_assembly.SLDASM, casing.SLDPRT, chassis_sub.SLDASM]
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2026-05-23 fix(cad): increase hole size to fit horn screws
    [sts3215_coaxial_stradded_bracket.SLDPRT]
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2026-05-23 fix(cad): remount PDB and battery to work with actual dimensions and fit brass inserts
    [100A power board.SLDPRT, bot_master_assembly.SLDASM, casing.SLDPRT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]
2026-05-23 fix(cad): modify SCB mounts to work with M2.5 brass inserts
    [casing.SLDPRT, chassis_sub.SLDASM]
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2026-05-23 fix(cad): increase chassis clearance for limbs
    [bot_master_assembly.SLDASM, casing.SLDPRT, chassis_sub.SLDASM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]
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2026-05-24 feat(cad): add M2 mounts for haa motors in casing and carry changes to derived parts
    [casing.SLDPRT, casing_back.SLDPRT, casing_front.SLDPRT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]
2026-05-26 fix(cad): remove PDB mount & increase clearance for HAA u bracket
    [casing.SLDPRT, casing_back.SLDPRT, casing_front.SLDPRT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]
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2026-05-28 fix(cad): resize horn-mount and brass-insert holes for M3 screws
    [sts3215_coaxial_stradded_bracket_haa.SLDPRT, sts3215_coaxial_stradded_bracket_hfe.SLDPRT]
2026-05-28 fix(cad): fix mounts for F683ZZ bearings
    [tibia.SLDPRT]
2026-05-28 fix(cad): adjust mouns for M3 screws on femur and shoiuydler following changes to brackets
    [femur.SLDPRT, shoulder.SLDPRT]
2026-05-28 fix(cad): adjust mouns for M3 screws on link tab
    [link_tab.SLDPRT]
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2026-05-29 fix(cad): increase tibia knee-joint hole clearance and increase integrity of turn-buckle attachment
    [limb_sub.SLDASM, tibia.SLDPRT]
2026-05-29 fix(cad): add a hole to femur to provide access to kfe servo mounting holes
    [femur.SLDPRT, limb_sub.SLDASM]
2026-05-29 fix(cad): decrease horn clearance in femur to allow for proper mounting
    [femur.SLDPRT, limb_sub.SLDASM]
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2026-05-29 fix(cad): fix hole sizes on hfe u-bracket
    [sts3215_coaxial_stradded_bracket_hfe.SLDPRT]
2026-05-29 chore(cad): carry recent fixes onto mirrored limb
    [femur.SLDPRT, limb_sub.SLDASM, mirrored_shoulder.SLDPRT]
2026-05-29 fix(cad): fix hole sizes on haa u-bracket
    [chassis_sub.SLDASM, sts3215_coaxial_stradded_bracket_haa.SLDPRT]
2026-05-29 chore(cad): carry all recent part fixes to assemblies
    [bot_master_assembly.SLDASM, chassis_sub.SLDASM, limb_sub.SLDASM]
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2026-06-04 fix(cad): resize battery to closer match real size
    [Battery.SLDPRT]
2026-06-04 feat(cad): rearrange middle casing to better fit existing parts + pi 5
    [casing.SLDPRT]
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2026-06-08 fix(cad): fix middle casing roof
    [casing.SLDPRT]
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2026-06-08 fix(cad): increase battery slot opening to accoutn for wire thickness
    [casing.SLDPRT]
2026-06-08 fix(cad): remove free casing walls to save material
    [casing.SLDPRT, casing_front.SLDPRT]
2026-06-08 fix(cad): raise pi mount and casing height
    [casing.SLDPRT]
2026-06-08 fix(cad): fix switch hole dimensions
    [casing.SLDPRT]
2026-06-08 feat(cad): modify roof cut to flatten front and back walls of middle casing
    [casing.SLDPRT]
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2026-06-11 fix(cad): casing fixes from iterating
    [casing.SLDPRT, casing_back.SLDPRT, casing_front.SLDPRT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]
2026-06-12 fix(cad): fix femur mounts form iterations
    [chassis_sub.SLDASM, femur.SLDPRT, limb_sub.SLDASM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]
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2026-06-12 fix(cad): add hole for wires in front casing and fix thin geometry
    [casing.SLDPRT, casing_front.SLDPRT, casing_middle.SLDPRT]
2026-06-18 fix(cad): fix femur sketch warning
    [femur.SLDPRT]
2026-06-18 fix(cad): fix mirrored limb issues
    [femur.SLDPRT, limb_sub.SLDASM, tibia_spherical_foot.SLDPRT]
2026-06-18 fix(cad): fix chassis subassembly
    [casing_front.SLDPRT, casing_middle.SLDPRT, chassis_sub.SLDASM]
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2026-06-25 fix(cad): fix urdf origin issues in assembly exporter configs
    [chassis_sub.SLDASM, limb_sub.SLDASM]
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2026-06-25 fix(cad): fix coordinate system in inverted shoulder
    [inverted_shoulder_link.STL, limb_sub.SLDASM]
2026-06-25 fix(urdf): fix inverted shoulder placement in urdf
    [inverted_shoulder_link.STL]
2026-06-25 fix(urdf): add appropriate inversion to femur joint on inverted shoudler side
    [limb.urdf.xacro]
2026-06-25 fix(cad): add end effector to the urdf mesh
    [limb_sub.SLDASM, limb_sub_new.SLDASM.urdf, tibia_link.STL]
2026-06-25 fix(urdf): add the missing end effector to xacro structure and remove redundant files
    [body_link.STL, chassis_sub.SLDASM.csv, chassis_sub.SLDASM.urdf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]
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2026-06-26 feat(ros/urdf): invert hfe back limb directions
    [robot.urdf.xacro]
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2026-07-01 fix(cad): make robot foot larger
    [chassis_sub.SLDASM, limb_sub.SLDASM, tibia.SLDPRT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]
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2026-07-01 chore(ros/bot_description): pass hardware info through xacro params as oppose to parsing yaml
    [robot.urdf.xacro, ros2_control.urdf.xacro]
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2026-07-02 feat(ros/bot_heardware): wire tick limits into xacro and access them from system interface
    [ros2_control.urdf.xacro]
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2026-07-02 fix(ros/bot_hardware): Fix write(which assumed ticks_to_rad(lower_ticks) was always the smaller radian bound.
    [sts_system_interface.cpp]
2026-07-02 fix(ros/bot_description): account for 90 degree offset of kfe
    [motor_params.yaml]
2026-07-02 fix(ros/bot_description): increase speed and acceleration limits
    [motor_params.yaml]
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
